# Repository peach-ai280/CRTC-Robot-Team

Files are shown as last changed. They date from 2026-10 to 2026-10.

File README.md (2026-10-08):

# CRTC2026 · 机器人总动员战队

重庆大学机器人训练大赛（CRTC2026）新生组参赛工程仓库。

## 📖 先看哪一份

| 你想知道什么 | 看这个 |
|---|---|
| **我们做到哪一步了、路上踩了哪些坑** | **➡ [`docs/工程日志.md`](docs/工程日志.md)** ← 主日志，按功能分板块写 |
| 进度总表、文档索引 | [`docs/00_总览与时间线.md`](docs/00_总览与时间线.md) |
| 用了哪些别人的东西 | [`docs/开源项目说明.md`](docs/开源项目说明.md) ← **中期提交必读** |
| 今天该干什么（内部备忘） | [`docs/现在该干什么.md`](docs/现在该干什么.md) |

---

## 关于文档规范（对照手册 4.3.1）

我们按手册要求组织文档，逐条对照如下：

| 手册要求 | 我们的做法 |
|---|---|
| 以 `.md` 格式提交 | 全部为 Markdown |
| 按设计进度**从早到晚**组织 | `docs/工程日志.md` 与各分册均按推进顺序排列 |
| **一个机器人功能 = 一个板块**，以**具体功能（H2 标题）+ 功能描述与开发历程**（正文）构成 | `docs/工程日志.md` 是主日志，每节 H2 即一个功能，正文分「功能描述」「开发历程」 |
| 每篇文档由**若干**上述板块组成 | 主日志含 11 个功能板块 |
| 用了开源项目须在**文档末尾完整说明** | 见 `docs/开源项目说明.md`，主日志末节也做了指引 |
| 仓库名用队伍名称的**英文/拼音** | `CRTC-Robot-Team`（Robot Mobilization） |
| 所有文档放在仓库根目录的 **`docs/`** 文件夹 | 根目录只留本 README，其余全在 `docs/` |

---

## 目录结构

```
CRTC-Robot-Team/
├── README.md                    本文件
├── docs/                        ★ 全部文档（中期考核「文档评估」提交内容）
│   ├── 工程日志.md               ★★ 主日志：11 个功能板块，一个功能一节
│   ├── 00_总览与时间线.md         进度总表、文档索引、真实性与开源说明
│   ├── 01_规则拆解与战术选型.md    得分规则量化、走桥战术、为什么放弃爬坡
│   ├── 02_机械结构与3D打印.md      尺寸红线核算、分层结构、打印件设计
│   ├── 03_底盘运动与麦轮防滑.md    麦轮解算、归一化限幅、死区、斜坡、电压补偿
│   ├── 04_电源硬件与焊接.md        电源树、继电器取电、DRV8833 改造、5V 塌陷
│   ├── 05_PS2手柄与遥控器.md       SPI 模式 3、DI/DO 接反、掉线保护、按键映射
│   ├── 06_舵机机构与抓取.md        序列器、舵盘转接板、夹爪、挑杆、探杆
│   ├── 07_方块携带与储仓.md        斜槽自锁、单向挡板、多项携带
│   ├── 08_半自动与视觉.md          机械对中 vs 视觉的选型、宏状态机、K210
│   ├── 09_结构稳定性成本与中期自查.md 跌落、尺寸复核、成本、考核自查表、视频脚本
│   ├── 开源项目说明.md           ★ 开源引用与许可，手册要求必写
│   ├── 进阶功能方案.md            3 项进阶功能 + 补买硬件清单 + 预算
│   ├── 调参指南.md                现场调参手册（分 8 步 + 症状速查 + 两套预设）
│   ├── 硬件接线与焊接指南.md       引脚总表、焊接点位、分步上电检查、故障速查
│   ├── 视觉模块选型与采购.md       K210 选型对比、接线、调试五步
│   ├── 半自动与全自动操作手册.md    三档模式怎么切、五个宏、全自动参数标定
│   ├── 代码说明_先看这个.md        代码文件导读
│   ├── 代码文件清单.md            逐文件清单
│   └── 现在该干什么.md            内部操作备忘（下一步清单）
├── firmware/                    ★ STM32 固件（C）
│   ├── Core/Inc/                   board.h 引脚映射 / config.h 全部可调参数 / 各模块头文件
│   ├── Core/Src/                   app.c 总调度 / mecanum.c 防滑 / motor.c 输出
│   │                               ps2.c / servo.c / arm.c / sensor.c / vision.c / auto_task.c
│   │                               bsp.c 时钟与外设初始化 / test_*.c 独立测试固件
│   ├── Core/Inc/hal_shim.h + Src/hal_shim.c   HAL 兼容层（纯寄存器，不依赖官方库）
│   ├── Core/Src/startup_stm32f103xb.c         用 C 写的启动文件（免官方汇编）
│   ├── STM32F103C8TX_FLASH.ld                 链接脚本
│   ├── 构建烧录与测试.md           一条命令出固件
│   ├── 烧录接口与ST-LINK说明.md    车上那 4 根 SWD 针怎么留
│   └── 编译与烧录指南.md           CubeIDE 图形化流程（备选）
├── cpp/                         ★ C++ 版运动 / 机械臂 / 视觉（离线验证，能在电脑上跑）
│   ├── README.md                  文件清单 + C vs C++ 的判断
│   ├── inc/crtc.hpp               类声明 + 参数结构 + 硬件抽象层接口
│   ├── src/                       chassis / motor / servo / arm / vision / params
│   ├── main_mcu.cpp                真机入口（串口命令，不接 PS2）
│   └── main_sim.cpp                离线自检用例（6 组断言）
├── mechanical/                  ★ 3D 打印件（参数化生成）
│   ├── gen_parts.py                结构件生成脚本（改尺寸改这里再重跑）
│   ├── gen_shell.py                外观套件生成器
│   ├── gen_gauge.py                底板量规
│   ├── 图纸集.html / 外观套件.html  带尺寸的图纸（浏览器打开）
│   ├── stl/*.stl                   25 个结构件
│   └── stl_pretty/*.stl            14 个外观件
├── 3D打印交付/                  ★ 拷去打印机就能开工（按批次分好文件夹）
│   ├── 打印机与耗材要求.md         机器能不能打的 4 条判定 + 耗材购买清单
│   ├── 打印前必读_金属底板适配.md   配 255×150 金属底板的三个必量数
│   ├── 切片与打印操作手册.md        零基础版：装软件→拖文件→填参数→切 gcode→上机
│   ├── 打印清单.csv               逐件的尺寸/重量/层高/填充/支撑
│   ├── 00_先打这个_量板规/ ~ 05_备件多打一份/
│   └── K1Max_G代码/               已切好的 G-code（K1 Max + PLA 直接打）
├── tools/                       ★ 自研工具链（本机没装 make / 切片软件，全自己写）
│   ├── build.py / build_cpp.py    一条命令编译
│   ├── flash.py                   一键烧录（check / motion / arm / vision / ps2 / full）
│   ├── slice_k1.py                自研切片器 → K1 Max 的 G-code
│   ├── check_gcode.py             切片结果逐行语法自检
│   ├── gen_step.py                导出 STEP（给机械队友改模型用）
│   ├── check_symbols.py           符号/宏静态自检
│   ├── print_bill.py              扫描 STL 出打印清单
│   ├── render_asm.py              用真实 STL 离线渲染装配示意图
│   └── sim/                       离线仿真（run_sim / run_auto_sim / run_cpp_sim）
└── vision/
    └── k210_find_cube.py          K210 MaixPy 色块识别（进阶功能备选）
```

---

## 三句话看懂我们的机器人

1. **两台一样的 4 轮麦轮车**（车体 236 × 162 × 148 mm；装收集铲后整车长 **283 mm**，
   红线 290 —— **只剩 7mm，是全车最紧的一条**）。
2. **1 号机走桥**抢中央高台的黄色能量核心（4 分 × 1.5 = 6 分），
   **2 号机在地面**扫 18 个白色能量单元（1 分 × 1.5 = 1.5 分/个）。
   **不走坡道** —— 麦轮在 26.6° 坡上会打滑，收益期望为负。
3. **半自动靠机械对中**（V 型口 + 双微动开关）而不是视觉，
   因为对中的失败模式是"没对准"（无害），视觉的失败模式是"对准了错的目标"（有害）。

---

## 技术栈与关键参数

| 项 | 值 |
|---|---|
| MCU | STM32F103C8T6 @ 72MHz |
| 底盘 | 4 × TT 马达(1:48) + 4 × 60mm 麦轮，轴距 180 / 轮距 136 mm |
| 驱动 | DRV8833 ×2（PHASE/ENABLE 接法），PWM 10kHz |
| 舵机 | MG995 ×1（大臂）+ SG90 ×3（夹爪/前铲/备用），PWM 50Hz |
| 遥控 | PS2 无线手柄，SPI 模式 3，281kHz |
| 电源 | 2 × 18650 串联（7.4V）→ 无线继电器 → 电机直供 + 5V 降压 |
| 控制周期 | 底盘 5ms / 舵机 10ms / 日志 200ms |
| 半轴距 / 半轮距 / 轮半径 | 0.090 / 0.068 / 0.030 m |

---

## 交付状态（截至 2026-10-08）

| 交付物 | 状态 |
|---|---|
| 开发环境与工具链 | ✅ **实测通过**（CubeIDE 2.2.0 + gcc 14.3.1 + 烧录器 + ST-LINK 驱动） |
| SWD 烧录链路 | ✅ **实测贯通**（`flash.py check` → `Device ID 0x410` / 3.21V） |
| 固件（底盘 / 防滑 / 机构 / 半自动 / 视觉接口） | 🟡 代码完成 + 离线仿真通过，**未上真车验证** |
| 3D 打印件 STL + 图纸集 | 🟡 模型完成（25 结构件 + 14 外观件），**未打印** |
| 接线表 / 焊接点位 / 上电检查 | 🟡 方案定稿，**未实际接线通电** |
| 工程日志 | ✅ `docs/工程日志.md` 主日志 + 15 份分册；标 `【待实测】` 处待实车回填 |
| 开源项目说明 | ✅ |
| 中期考核视频（1080p / 30fps） | ⬜ 待拍摄（脚本见 `docs/09`） |
| 规则测评（80 道单选） | ⬜ 待全队刷题库 |

---

## 提醒（给自己看的）

- 刷固件前**务必改 `config.h` 里的 `ROBOT_ID`**（1 = 1 号机，2 = 2 号机）。
- 所有 `【待实测】` / `【待回填】` 标记处，实车验证后必须替换成真实数据，**不能留着设计值冒充实测值**。
- 无线继电器**过了中期考核再买**（手册明确：未通过中期测评的队伍无需购买）。
- 中期提交截止 **2026-10-19 24:00**，收件 `zhang.guohao@lark.cquqian.li`。

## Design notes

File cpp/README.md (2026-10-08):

# C++ 版：运动 / 机械臂 / 视觉

> 这一套是应你"理论上应该用 C++"的要求写的。我在下面先把**该不该用 C++**
> 的判断讲清楚，再逐份说明每个文件是干什么的、你要对它们做什么。

---

## 一、先说判断：固件用 C 是对的，但不是因为"懒"

你说"理论上应该用 C++ 吧"——这个直觉**一半对一半不对**，我分开说：

**不对的一半**：STM32 固件本体用 C 是工程上的正解，不是退而求其次。

- HAL 库、CubeMX 生成的代码、ST 的所有例程全是 C API。用 C++ 只是给 C 函数包一层壳，没有实际收益。
- 关掉异常和 RTTI（否则 64KB Flash 顶不住）之后，C++ 能用的就只剩"类 + 内联"。而这套代码压根没有复杂的类层次，封装带来的收益接近零。
- 队友接手、老师检查代码时，C 的门槛低得多。

**对的一半**：**算法层和离线验证用 C++ 确实更好**。这也是我写这一套的原因：

1. **一套代码两个目标**。`hal_mcu.cpp` 和 `hal_sim.cpp` 是同一个接口的两份实现，同一份 `chassis.cpp` / `arm.cpp` / `vision.cpp` 换个文件就能在 PC 上跑。C 版做不到这点——C 版的仿真是另写了一份 `sim_kinematics.c`，等于同一套公式写了两遍，**真机代码和仿真代码会慢慢跑偏**，这是个真实的长期隐患。
2. 参数做成结构体，以后要"扫一组参数看哪个最好"很方便。
3. 类的边界（底盘 / 电机 / 舵机 / 序列器 / 视觉）比 C 版的文件划分更清晰，出问题好定位。

**所以结论**：两套并存，各干各的——

| 场景 | 用哪套 |
|---|---|
| 打比赛、接 PS2 手柄 | **C 版**（`firmware/build/full/firmware.bin`） |
| 学逻辑、改算法、离线验证参数 | **C++ 版**（这一套） |

⚠ **C++ 版目前没有接 PS2 手柄**，只收串口字符命令。它不替代 C 版，是给你验证和试参数用的。

⚠ **两套的参数必须同步改**：`firmware/Core/Inc/config.h` ↔ `cpp/src/params.cpp` 一一对应。只改一边会出现"同一个动作两套表现"的怪事。

---

## 二、上一轮给的那些文件，分别是啥？哪个才是要烧进去的？

**只有 `.bin`（或 `.hex` / `.elf`）是烧进芯片的东西。`.c` / `.h` / `.py` / `.md` 都不是**——它们是"原料"，编译之后才变成能烧的文件。

| # | 文件 | 它是什么 | 要烧吗 | 你要干啥 |
|---|---|---|---|---|
| 1 | `firmware/构建烧录与测试.md` | 说明书：怎么编、怎么烧、三个测试固件怎么用 | ❌ 不烧 | **照着做**。第一步就看这个 |
| 2 | `firmware/Core/Inc/config.h` | **全车唯一调参入口**，每个宏后面都写了"调大/调小的后果" | ❌ 不烧（它是被编进去的原料） | **调试期间 95% 的时间只改这个文件**，改完重编 |
| 3 | `tools/build.py` | C 版构建脚本（本机没 make，用 Python 直接调编译器） | ❌ 不烧 | 在**仓库根目录**敲 `python tools/build.py full`（别在 `cpp/` 里敲，那里没有 `tools/`） |
| 4 | `firmware/Core/Src/test_motion.c` | 底盘测试固件的**源码** | ⚠️ 编译后烧它的 `.bin` | 架空车，串口发 `w/a/s/d/q/e` 看轮子转向 |
| 5 | `firmware/Core/Src/test_arm.c` | 机构测试固件的**源码** | ⚠️ 编译后烧它的 `.bin` | 发 `1`~`7` 试姿态，`i/k` 微调角度 |
| 6 | `firmware/Core/Src/test_vision.c` | 视觉测试固件的**源码** | ⚠️ 编译后烧它的 `.bin` | 不接摄像头也能测：发 `t/y/n` 造自造帧 |
| 7 | `firmware/Core/Inc/hal_shim.h` | 我自己写的 HAL 兼容层（官方库下不下来） | ❌ 不烧（被编进去） | **不用动**。业务代码一行没改就跑起来了 |
| 8 | `firmware/build/full/firmware.bin` | **★ 唯一真正烧进芯片的文件**（完整版，带 PS2） | ✅ **就是它** | 用 CubeIDE 或 STM32CubeProgrammer 烧到 `0x08000000` |

### 四个 `.bin` 不是都要烧，是按阶段换

```
第 1 天  firmware/build/motion/firmware.bin  → 架空车，只验证底盘转对不转
第 2 天  firmware/build/arm/firmware.bin     → 只验证舵机和机构
第 3 天  firmware/build/vision/firmware.bin  → 只验证视觉串口解析
打比赛   firmware/build/full/firmware.bin    → 全部功能，接 PS2 手柄
```

每次换固件就是重新烧一遍，芯片里同一时刻只有一个程序。

---

## 三、C++ 版每一份文件：干啥的 + 你要干啥

| 文件 | 干什么的 | 你要对它做什么 |
|---|---|---|
| `cpp/inc/crtc.hpp` | 全部类的声明 + `Params` 参数结构 + 硬件抽象层接口 | 读一遍理解结构，**一般不用改** |
| `cpp/src/params.cpp` | 默认参数表（和 `config.h` 一一对应） | ⚠️ **标定后把实测值抄回这里** |
| `cpp/src/chassis.cpp` | 底盘四步管线：斜坡 → 限自转 → 麦轮逆解 → 归一化 | 一般不用改 |
| `cpp/src/motor.cpp` | 单轮输出：死区补偿 → 起步助力 → 电压补偿 → 拆 PWM/方向 | 一般不用改 |
| `cpp/src/servo.cpp` | 舵机限速缓动（防 5V 塌陷导致单片机复位） | 一般不用改 |
| `cpp/src/arm.cpp` | 八个动作脚本 + 串行动作序列器 | ⚠️ **舵机角度标定完抄回这里** |
| `cpp/src/vision.cpp` | 14 字节定长帧解析 + 自动对位的 P 控制 | 一般不用改 |
| `cpp/src/hal_mcu.cpp` | 硬件抽象层的**真机实现**（碰寄存器） | 不用动 |
| `cpp/src/hal_sim.cpp` | 硬件抽象层的**模拟器实现**（写内存） | 不用动 |
| `cpp/main_mcu.cpp` | 真机入口 + 串口命令表 + 主循环调度 | 想加串口命令改这里 |
| `cpp/main_sim.cpp` | 离线自检用例（6 组断言） | 想加测试改这里 |
| `tools/build_cpp.py` | C++ 版构建脚本 | 敲命令 |
| `tools/sim/run_cpp_sim.py` | 模拟器驱动（读日志 + 判 PASS/FAIL） | 敲命令 |

**一句话概括你要动的**：`params.cpp`（参数）+ `arm.cpp`（角度）+ 敲两条命令。

---

## 四、三条命令（可直接复制）

```bash
# 1. 编模拟器版 + 在 PC 上跑一遍自检（改完参数先用这个验证）
python tools/build_cpp.py sim
C:/Users/hp/.workbuddy/binaries/python/envs/default/Scripts/python.exe tools/sim/run_cpp_sim.py

# 2. 编真机固件（出 cpp/build/mcu/firmware.bin）
python tools/build_cpp.py mcu

# 3. 两个一起编
python tools/build_cpp.py all
```

第 2 条必须用那个带 unicorn 的 Python（装在 WorkBuddy 的虚拟环境里，没污染你的系统 Python）。

---

## 五、C++ 版固件的串口命令

烧 `cpp/build/mcu/firmware.bin`，串口 PA9/PA10、115200，**发一个字符即可，不用回车**。

```
运动： w 前进  s 后退  a 左移  d 右移  q 左转  e 右转  x 停  z 斜走45°  r 自动演示
机构： 1 收起  2 待命  3 地面取块  4 台阶取块  5 入仓  6 挑物资架  7 洞窟  8 放铲
微调： [ ] 夹爪∓5°   - = 大臂∓5°   , . 前铲∓5°   m 打印当前角度
视觉： v 造一帧测试数据（不接摄像头也能验证）   V 打印视觉状态
其他： h 帮助   0 急停解除
```

**微调完的角度要抄回 `cpp/src/arm.cpp`**（或 C 版的 `config.h`），否则下次烧录又回默认值——这是新手最容易白干的一件事。

---

## 六、模拟器实测数据（ARM 机器码真跑出来的，不是我推算的）

```
[1] 麦轮解算
  纯前进   [+0.850 +0.850 +0.850 +0.850]   四轮同号同值 ✓
  纯左移   [-0.850 +0.850 +0.850 -0.850]   LF/RB 负、RF/LB 正 ✓
  斜走45°  [+0.000 +1.000 +1.000 +0.000]   ← 注意这个
  三轴全给 [-0.218 +1.000 +0.564 +0.218]   |w|max=1.000（归一化生效）

[2] 方向保持：反算角 vs 期望角，误差 0.000°（全部用例）

[3] 斜坡：0 → 95% 用 270ms（理论 283ms）；松手 → 停住 145ms

[4] 死区：speed 0.05 → duty 0.341；0.50 → 0.710；1.00 → 1.000

[5] 地面取块序列：耗时 3970ms，同一时刻最多 1 个舵机在动 ✓

[6] 视觉：好帧解析正确（含负数坐标）；坏校验被丢弃；垃圾数据后能重新对齐
```

**斜走 45° 那行值得单独解释**：四轮解算是 `[0, 1, 1, 0]`，即**只有右前和左后两个轮在转**。这不是 bug，是麦轮的固有特性——纯对角线移动时只有一条对角线上的两个轮出力，另外两个轮速度为 0。看到这个不要以为是代码错了。

**3970ms 一个取块动作偏慢**，5 分钟一局大约能取 20 多个。想加快有两个旋钮：把 `servoDps` 从 240 提到 360（前提是不烧舵机、不拉塌 5V），或者把 `arm.cpp` 里各步的 `waitMs` 调小。建议先只改 `waitMs`，风险小。

---

## 七、这套代码我验证了什么、没验证什么

**已验证（本机实测）**：

- ✅ C++ 真机固件编译链接通过，25.3KB Flash / 3.3KB RAM（芯片 64KB，余量充足）
- ✅ 模拟器里执行真实 ARM 机器码，6 组断言全 PASS
- ✅ 运动学方向、归一化、斜坡、死区、序列串行性、视觉帧解析

**没验证（要你上电实测）**：

- ❌ 舵机角度——这是按机构几何推的初值，你的装法不同，必须在线标定
- ❌ 真机跑起来的实际表现（打滑、跑偏、夹不夹得住）
- ❌ 视觉对真实 K210（我只验证了自己造的帧能被正确解析）
- ❌ PS2 手柄——C++ 版根本没接，打比赛用 C 版

**上电前三条**：① 车架空 ② 电池 ≥7.0V ③ DRV8833 的 nSLEEP 接高。舵机听到"吱吱"声立刻断电，那是超行程在硬撑。

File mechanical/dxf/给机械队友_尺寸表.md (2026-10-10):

# CRTC2026 · 结构件尺寸表（交给机械队友）

> 单位 mm ｜ 材料 PLA ｜ 生成脚本 `mechanical/gen_parts.py`（改完重跑，图纸和 STL 同源，不会跑偏）
>
> **每个件都是「2D 轮廓 + 拉伸」**，所以一张 DXF 就是这个件的完整定义。
> 改图流程：用 SolidWorks / Fusion 360 / Creo 打开 `零件名.dxf` → 选中外面的闭合轮廓 →
> **拉伸到【厚度】那一列的数值** → 再把 DXF 里剩下的闭合小环（也就是孔）拉伸切除。
> 想一次看全部就用 `ALL_全部零件.dxf`，每个零件一个图层，图层名末尾带厚度。

## ⚠ 哪些尺寸不能动（规则红线，改了会判不过）

- **整车外廓**：初始状态 ≤ 290 × 195 × 210 mm（长×宽×高），变形后 ≤ 445 × 400 × 450
- **整车重量** ≤ 2.0 kg（目前预算 1076 g，余 924 g，余量建议拿去做底部配重）
- 甲板宽 162 mm 是贴着 195 上限留了余量，加宽前先确认还有多少裕度

## ✅ 哪些随你改（不影响规则）

- `01_deck_front` / `02_deck_rear` 上的**安装长圆槽**：这是给金属底板留的调节量，位置/长度随便调
- 所有减重孔的位置（只要别和安装槽、舵机槽撞在一起）
- 外观件（`stl_pretty/` 那批）全部不承重，随便改形状

## 📐 全车已经定死的机械接口（改了要同步改代码）

| 参数 | 值 | 谁在用 |
|---|---|---|
| 轮距 TRACK | 136 mm（半 68） | `firmware/Core/Inc/board.h` 的 `ROBOT_HALF_TRACK` |
| 轴距 WHEELBASE | 180 mm（半 90） | `board.h` 的 `ROBOT_HALF_WHEELBASE` |
| 麦轮外径 | 60 mm（半径 30） | `board.h` 的 `WHEEL_RADIUS` |
| 能量单元 | 30 mm 立方（V1.5），**六面各开 15×15 方口、内部贯通** | 夹爪闭合净距、收集铲喉口 50 mm |
| 机械臂平行杆轴距 AB_LINK_L | 105 mm | 臂长，改了够不到离地 250 的物资架 |
| 机械臂两轴距 AB_PITCH | 24 mm | 肩架竖板与肘座**必须同时**是 24 |
| 机械臂回转轴位置 AB_AX | 底板中心往前 106 mm | 收起时臂朝正后方平躺 |
| 机械臂轴高 A.z | 离地 164.5 mm | 收起态全车最高 196.5（红线 210） |
| 收起时爪子中心落点 | x = −17 mm（yaw 180°） | 储仓最后一列必须盖住这个点 |
| 储仓装车位置 | x ∈ [−32, +68]，y ∈ [−68, +68] | 中段立柱已挪到 x=−45/+78 让位 |
| 储仓有效容量 | 3 列 × 4 排 = 12 位，**最后列中两排留空** → 实装 10 块 | 那两格是爪子停车位兼投料口 |
| 安装长圆槽 | 中心 ±60，槽长 30，槽宽 4 | 只此一项和买来的金属底板有关 |

## 零件清单

| DXF 文件 | 中文名 | 数量 | 长 | 宽 | 厚度 | 估重 | 批次 |
|---|---|---|---|---|---|---|---|
| `01_deck_front.dxf` | 前段主甲板 | ×1 | 128 | 162 | 4.0 | 36.2 g | ① 底盘必打 |
| `02_deck_rear.dxf` | 后段主甲板 | ×1 | 128 | 162 | 4.0 | 38.3 g | ① 底盘必打 |
| `03_deck_splice.dxf` | 甲板搭接板 | ×1 | 60 | 60 | 3.0 | 5.9 g | ① 底盘必打 |
| `04_column.dxf` | 甲板立柱 | ×4 | 12 | 12 | 22.0 | 1.3 g | ① 底盘必打 |
| `05_scoop_floor.dxf` | 收集铲底板（V 型） | ×1 | 28 | 96 | 6.0 | 6.5 g | ② 收集与储仓 |
| `05b_scoop_wall_L.dxf` | 收集铲侧板（左） | ×1 | 28 | 29 | 26.0 | 2.3 g | ② 收集与储仓 |
| `05c_scoop_wall_R.dxf` | 收集铲侧板（右） | ×1 | 28 | 29 | 26.0 | 2.3 g | ② 收集与储仓 |
| `05d_scoop_back.dxf` | 收集铲后壁（对中挡板） | ×1 | 8 | 64 | 26.0 | 7.2 g | ② 收集与储仓 |
| `06_limit_lever.dxf` | 对中限位摆杆 | ×2 | 45 | 12 | 4.0 | 1.2 g | ③ 机械臂（柱坐标） |
| `07_grip_finger_L.dxf` | 夹爪指（左） | ×1 | 46 | 16 | 6.0 | 1.7 g | ③ 机械臂（柱坐标） |
| `08_grip_finger_R.dxf` | 夹爪指（右） | ×1 | 46 | 16 | 6.0 | 1.7 g | ③ 机械臂（柱坐标） |
| `24a_claw_base.dxf` | 平行夹爪·爪架底板 | ×1 | 74 | 56 | 4.0 | 4.6 g | 其他 |
| `24b_claw_slider.dxf` | 平行夹爪·滑块 | ×2 | 18 | 16 | 12.0 | 1.8 g | 其他 |
| `24c_claw_finger.dxf` | 平行夹爪·爪指 | ×2 | 6 | 26 | 34.0 | 2.7 g | 其他 |
| `24d_claw_horn.dxf` | 平行夹爪·舵机摇臂 | ×1 | 33 | 6 | 3.0 | 0.3 g | 其他 |
| `24e_claw_link.dxf` | 平行夹爪·连杆 | ×2 | 34 | 6 | 3.0 | 0.3 g | 其他 |
| `24f_claw_gear.dxf` | 齿轮夹爪·齿轮 | ×2 | 15 | 15 | 6.0 | 0.3 g | 其他 |
| `24g_claw_rack.dxf` | 齿轮夹爪·齿条滑块 | ×2 | 44 | 15 | 12.0 | 3.8 g | 其他 |
| `24i_claw_finger_gear.dxf` | 齿轮夹爪·爪指 | ×3 | 6 | 36 | 34.0 | 3.9 g | 其他 |
| `24h_claw_base_gear.dxf` | 齿轮夹爪·爪架底板 | ×1 | 74 | 56 | 4.0 | 3.8 g | 其他 |
| `26_cube_mock.dxf` | 能量块道具 30×30×30（镂空骨架） | ×4 | 30 | 30 | 30.0 | 7.4 g | 其他 |
| `30_arm_base.dxf` | 机械臂·回转底座（柱坐标） | ×1 | 64 | 44 | 40.0 | 15.2 g | ③ 机械臂（柱坐标） |
| `31a_arm_turntable.dxf` | 机械臂·回转盘（柱坐标） | ×1 | 64 | 44 | 6.0 | 6.9 g | ③ 机械臂（柱坐标） |
| `31b_arm_mast.dxf` | 机械臂·立柱（柱坐标） | ×1 | 40 | 40 | 62.6 | 15.5 g | ③ 机械臂（柱坐标） |
| `32_arm_carriage.dxf` | 机械臂·滑座（柱坐标） | ×1 | 52 | 52 | 32.0 | 10.9 g | ③ 机械臂（柱坐标） |
| `33_arm_boom.dxf` | 机械臂·爪横臂（柱坐标） | ×1 | 38 | 24 | 8.0 | 4.0 g | ③ 机械臂（柱坐标） |
| `34_arm_lift_crank.dxf` | 机械臂·升降曲柄（柱坐标） | ×1 | 18 | 28 | 8.0 | 1.4 g | ③ 机械臂（柱坐标） |
| `35_arm_lift_link.dxf` | 机械臂·升降连杆（柱坐标） | ×1 | 56 | 8 | 6.0 | 1.2 g | ③ 机械臂（柱坐标） |
| `36_arm_lift_cap.dxf` | 机械臂·顶帽（柱坐标） | ×1 | 60 | 60 | 6.0 | 7.1 g | ③ 机械臂（柱坐标） |
| `12_bin_floor.dxf` | 储仓底板 | ×1 | 100 | 136 | 3.0 | 22.0 g | ② 收集与储仓 |
| `13_bin_side.dxf` | 储仓侧板 | ×2 | 100 | 52 | 3.0 | 8.1 g | ② 收集与储仓 |
| `14_bin_divider.dxf` | 储仓隔板 | ×2 | 130 | 46 | 3.0 | 7.6 g | ② 收集与储仓 |
| `15_bin_flap.dxf` | 储仓单向挡板 | ×3 | 42 | 30 | 2.0 | 1.3 g | ② 收集与储仓 |
| `16_rack_hook.dxf` | 物资架挑杆头 | ×1 | 70 | 24 | 6.0 | 3.5 g | ③ 机械臂（柱坐标） |
| `17_cave_probe.dxf` | 洞窟探杆头 | ×1 | 92 | 20 | 6.0 | 3.8 g | ③ 机械臂（柱坐标） |
| `18_electronics_tray.dxf` | 电控托盘 | ×1 | 110 | 80 | 3.0 | 12.7 g | ① 底盘必打 |
| `19_battery_clip.dxf` | 18650 电池盒卡箍 | ×1 | 54 | 52 | 3.0 | 1.9 g | ① 底盘必打 |
| `20_bumper_front.dxf` | 前保险杠 | ×1 | 16 | 108 | 10.0 | 7.4 g | ① 底盘必打 |
| `21_anti_tip.dxf` | 防翻侧杆 | ×2 | 116 | 16 | 5.0 | 4.6 g | ① 底盘必打 |
| `22_ramp_anchor.dxf` | 坡道防滑撑地块 | ×1 | 48 | 24 | 8.0 | 4.7 g | ② 收集与储仓 |
| `23_cam_mast.dxf` | 视觉模块支架 | ×1 | 118 | 36 | 4.0 | 8.2 g | ③ 机械臂（柱坐标） |

## 联系与背景

重庆大学 CRTC2026 机器人训练大赛，新生组。电控这边已经把固件写完（STM32F103C8T6，
DRV8833 驱动、麦轮 X 型逆解、PS2 半自动 + 全自动），**不依赖任何 3D 件的精确尺寸**，
唯一的要求是上面那张「不能动的机械接口」表里的四个数别变。

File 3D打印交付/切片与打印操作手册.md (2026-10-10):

# 3D 打印：从 STL 到实物（零基础版）

> **⚠️ 先读 `打印前必读_金属底板适配.md`**（就放在同一层目录里）。
> 里面写了配你那块 255×150 金属底板要先量的三个数，以及全车唯一一个
> 必须对上的孔位（甲板立柱，140×100）。**那份读完再回来照这份点鼠标。**

> 这一份是给你（或帮你打印的学长）照着点鼠标用的。
> 全程不需要写代码，不需要懂建模。
> **唯一需要你先确认的一件事：你们那台打印机的牌子型号。** 写在下面，参数才好填准。

> 📦 **不知道机器能不能打、不知道买什么料 → 先看 `打印机与耗材要求.md`**（同一层目录）。
> 里面有：能不能用这台机器的 4 条判定、耗材照抄购买清单、为什么必须 FDM 不能用光固化。

---

## 0. 先回答三个问题（决定后面怎么填参数）

| 问 | 怎么确认 | 填什么 |
|---|---|---|
| 打印机型号？ | 看机身上的铭牌 | ______ |
| 打印床多大？ | 量一下能打的最大方块，常见 220×220 或 235×235 | ______ |
| 用的什么料？ | 看料盘上写的，通常是 **PLA** | ______ |

> 我们最大的件是 `02_deck_rear.stl`（128×162mm），**220mm 的床放得下**。
> 甲板之所以分成前后两段，就是因为一整块 236mm 超床了。

---

## 1. 装切片软件（三选一，装一个就行）

| 软件 | 费用 | 推荐度 | 下载 |
|---|---|---|---|
| **OrcaSlicer** | 免费 | ★★★★★ 首选，中文界面全 | 搜 "OrcaSlicer 官网" → GitHub Releases 下 Windows 版 |
| PrusaSlicer | 免费 | ★★★★ 稳，就是有些国产机没配置 | prusa3d.com |
| Ultimaker Cura | 免费 | ★★★ 老牌，机型多，界面稍旧 | ultimaker.com |

**装的时候会让你选打印机型号**——选你们那台。列表里找不到就选一个床尺寸一样的通用机型（比如 "Ender-3"，床 220×220），后面手动把床尺寸核对一遍。

---

## 2. 导入零件

1. 打开软件，左上角确认打印机型号对了
2. 把**这一批要打的**文件夹里的 `.stl` 全选，**直接拖进软件窗口**
   （第一批到底打哪个文件夹，看第 8 节——**不是**直接打 `01_底盘必打`）
3. 弹出"导入多个对象"→ 选 **"作为一个对象，包含多个零件"**（OrcaSlicer）或 "单个模型，多部件"（Cura）
   - 这样后面可以一个一个分开摆

> **不要一次导入全部 39 个。** 一次摆 5~8 个最好操作，摆错了也只重摆几个。

### ⚠ 导入前先看清"数量"——有些件要打好几个

`打印清单.csv` 里有**「数量」**这一列，别漏了：

| 批次 | 文件数 | **实际要打的件数** |
|---|---|---|
| ① 底盘必打 | 8 | **12** |
| ② 收集与储仓 | 9 | **13** |
| ③ 机械臂与机构 | 14 | **15** |
| ④ 外观套件 | 14 | 14 |
| 合计 | 45 | **54** |

比如 `06_limit_lever`（对中摆杆）要打 **2 个**（左右各一），
`07_grip_finger_L` / `08_grip_finger_R` 各 1 个（注意是左右两件、不是同一个件打两个）。

⚠ 上面这张表以 **`打印清单.md` 为准**（那份是脚本生成的，本手册写到后面可能会滞后）。
零件数变了就重跑 `python tools/print_bill.py` 刷新。

**在切片软件里怎么打多个**：选中那个件 → 右键 → **"复制" / "Multiply" / "数量"** → 填 2 或 3，
软件会自动摆开。**不要**分两次切片打，那要重新预热两遍，慢一倍。

另外有 5 个件标了 **「建议多打一份」**（`05_备件多打一份` 文件夹里的）：
立柱、对中摆杆、夹爪指×2、舵盘转接板。这几个是摔断/滑牙的高发件，
多打一份放在工具盒里，赛场上断了能直接换。

---

## 3. 摆放（这一步最容易出错，认真看）

### 三条铁律

**① 最大的那个面朝下贴床。**
薄板件（甲板、储仓底板、侧裙）本来就是平躺的，导入后点一下工具栏的 **"放到平台上"**（图标是个小方块落到网格上），软件会自动摆正。

**② 别让件悬空。**
悬空的部分打印时需要支撑，拆支撑很麻烦还留疤。所以：
- 夹爪指、对中摆杆这种细长件 → **躺着放**，别立着
- 轮眉是弧形的 → **开口朝上**放（弧顶朝下贴床）

**③ 件和件之间留 5mm 以上。**
挨太近会粘在一起，掰开时容易断。

### 快速摆放按钮（OrcaSlicer）

左工具栏从上往下：
- 第 2 个 **移动** → 选中件拖动
- 第 3 个 **缩放** → **不要动！** 我们给的尺寸就是实际尺寸，缩放错了装不上
- 第 4 个 **旋转** → 点件，选 **"放到平台上"**（自动躺平）
- 第 5 个 **分割/排列** → 点 **"自动排列"**，软件帮你把件铺满一床

---

## 4. 打印参数（照抄，别自己改）

在右侧参数面板里选 **"0.20mm 标准"** 这类预设，然后手工核对这几项：

| 参数 | 填什么 | 为什么 |
|---|---|---|
| 层高（Layer height） | **0.20mm**（外观件 0.16mm） | 0.2 是强度和速度的平衡点；0.1 太慢，0.3 太糙 |
| 壁厚 / 外壳圈数（Wall loops） | **3 圈** | 少于 2 圈一掰就裂 |
| 顶部/底部层数 | **4 层** | 薄板件的强度全靠它俩 |
| 填充密度（Infill） | **25~30%**（外观件 15%） | 受力件别低于 25%；外观件不承重，15% 省料省时 |
| 填充图案 | **网格 / Grid**（或 Gyroid） | 三向受力都扛得住 |
| 支撑（Support） | **关**（大件开"边缘支撑/brim"） | 我们的件都设计成不用支撑的；大件怕翘边就加 **Brim 8mm** |
| 喷嘴温度 | **200℃**（PLA，第一层 205） | 料盘上写了就按料盘 |
| 热床温度 | **60℃**（第一层 65） | 低于 55 会翘边脱落 |
| 打印速度 | **50~60 mm/s**，首层 **20 mm/s** | 首层慢是粘床的关键 |
| 冷却风扇 | **100%**（首层 0%） | 首层开风扇会翘 |

> 这些数在 `docs/02_机械结构与3D打印.md` 里也有，那里还有我们踩过的坑。

---

## 5. 切片 & 导出

1. 右上角点 **"切片"**（Slice）
2. 等几秒，下方会显示 **预计用时** 和 **用料克数** ← **这两个数记下来，填回 `打印清单.csv`**
3. 切片完会显示层预览，拖滑块看一遍：
   - 有没有大片悬空没支撑
   - 首层铺得实不实
4. 点 **"导出 G-code"**（或"保存到可移动驱动器"）
5. 存成 `01_deck.gcode` 这种名字，拷到 **SD 卡根目录**（不是文件夹里）

---

## 6. 上机打印

1. SD 卡插打印机
2. 屏幕选 **Print from SD** → 找到文件名 → 确认
3. **前 5 分钟别走开**，盯着首层：
   - 丝均匀地压在床上、边缘不翘 → 成了，可以走
   - 丝卷成球 / 挤出不来 → 立刻停，床没调平或喷嘴太高
4. 打完等床降到 **40℃ 以下**再取件（热的时候取会变形）
5. 取不下就用铲刀慢慢撬，**别硬掰**

---

## 7. 打完之后：试装（这一步一定做）

打完第一批底盘件，立刻拿螺丝试装：

- **M3 孔插不进螺丝** → 正常，用 **3mm 钻头**手动扩一下（打印件孔会缩）
- **孔位对不上** → 先用记号笔描一下再扩成长孔，别推倒重打
- **件太松** → 加个 M3 螺母或垫片

> 打印件有 ±0.2mm 的误差是**正常的**，不是设计错了。
> 我们的孔都故意留了余量，就是给你扩的。

---

## 8. 打印顺序（照这个来，一件都不会白打）

> ⚠️ **先看这条**：`01_底盘必打` 里有 **3 个"尺寸还没定死"的文件**——
> `01_deck_front`、`02_deck_rear`、`04_column`。它们的立柱槽位（±45~75mm 长圆槽）和立柱高度（22mm）
> 取决于你手上那块金属底板的**实测宽度和离地高度**（见 `打印前必读_金属底板适配.md`）。
> 先打它们有白打的可能（两块甲板 77g / 4~5 小时，是全车最贵的件），所以把第 0 批提到最前。

| 序号 | 打什么 | 在哪 | 文件 / 件数 | 约重 | 大约用时 |
|---|---|---|---|---|---|
| **0** | **量板规（必须最先）** | `00_先打这个_量板规/` | 3 文件 / 3 件 | <20 g | 8 分钟 |
| **1** | 底盘里**不依赖板宽**的 6 件 | `01_底盘必打/` | 5 文件 / 6 件（见下表） | ≈ 43 g | 2~3 小时 |
| **2** | 收集与储仓 | `02_收集与储仓/` | 8 文件 / 12 件 | 91 g | 5~7 小时 |
| **3** | 机械臂与机构 | `03_机械臂与机构/` | 9 文件 / 12 件 | 40 g | 4~6 小时 |
| **4** | **等量规结果再打** | `01_底盘必打/` | 3 文件 / 6 件 | 81 g | 4~5 小时 |
| **5** | 备件 | `05_备件多打一份/` | 5 文件 / 5 件 | ≈ 15 g | 2 小时 |
| **6** | 外观套件 | `04_外观套件/` | 14 文件 / 14 件 | 72 g | 6~8 小时 |

> 注：第 5 批里的 `04_column.stl`（立柱备件）和第 4 批的立柱是同一个件，
> 同样要等量规结果；其余 4 个备件（摆杆、夹爪指×2、舵盘转接板）随时可打。

### 第 1 批具体打这 6 件

从 `01_底盘必打` 里只挑下面 5 个文件，**其余 3 个先别动**：

| 文件 | 件数 | 是什么 |
|---|---|---|
| `18_electronics_tray.stl` | 1 | 电控托盘 |
| `19_battery_clip.stl` | 1 | 18650 电池卡箍 |
| `20_bumper_front.stl` | 1 | 前保险杠，**加 Brim 8mm** |
| `21_anti_tip.stl` | 2 | 防翻侧杆，左右各一 |
| `03_deck_splice.stl` | 1 | 甲板搭接板（垫在接缝下的方块，不受板宽影响）|

**第 4 批（等量规）**：`01_deck_front`、`02_deck_rear`、`04_column`×4。
量完把四个结果发出来，参数定稿、重出图之后这几件再打——**前面打的件一件都不会白费**。

> 文件数 ≠ 件数：对中摆杆打 2 个、舵盘转接板 3 个、储仓侧板/隔板各 2 个……见第 2 节数量表。

> **外观件一定最后打。** 中期考核看的是功能，外壳再漂亮、车跑不起来也是 0 分。
> 而且外观件装完要重新称重（限重 2.0kg），早装了反而碍事。

## 9. 打完要称一次总重

**整车限重 2.0kg。** 打印件估算总重 **324g**（39 个文件 / 实际要打 50 件）。

整车重量是逐项算出来的，不是拍脑袋：

| 项目 | 小计 |
|---|---|
| 3D 打印件（50 件） | 324 g |
| 金属底板 255×150×1.5 铝板 | 155 g |
| TT 马达 ×4 + 麦轮 ×4 | 312 g |
| 电池 ×2 + 电池盒 | 105 g |
| 舵机（MG995 ×1 + SG90 ×3） | 82 g |
| STM32 / DRV8833 ×2 / PS2 接收头 | 24 g |
| 洞洞板、线材、螺丝、开关、杂件 | 74 g |
| **合计** | **≈ 1076 g** |

**距 2.0kg 上限还余约 924g。** 这个余量是**要主动用掉的**——麦轮车重心越低越防滑，
按 `docs/02` 的建议再配 200~300g 底部配重后约 1326g，仍有 674g 余量。

> ⚠ 早期这里写"1.6~1.9kg"是高估了，会导致你不敢加配重、车太轻反而打滑。
> 电子件按典型值估，**装完第一件事就是上秤**，实数填回 `docs/09`。

**装完外观件后必须实称一次。** 超了就按这个顺序拆：
1. 顶盖（约 16g）
2. 尾板 + 三角支臂（约 4g）
3. 侧裙（约 15g）

---

## 10. 常见翻车现场

| 现象 | 原因 | 怎么办 |
|---|---|---|
| 首层就翘起来、脱落 | 床没调平 / 床温低 / 首层有风扇 | 重新调平，床温 60，首层关风扇，加 Brim |
| 件中间裂开一道缝 | 填充太低或圈数太少 | 填充提到 30%，壁厚 3 圈 |
| 表面一层一层的、有疙瘩 | 料受潮了 | PLA 受潮要烘干（60℃ 烤箱 4 小时）或用新料 |
| 打出来尺寸偏小，孔更小 | 正常收缩 | 3mm 钻头扩孔 |
| 细长件立着打，一碰就断 | 摆放方向错了 | 躺着打，层纹方向要顺着受力方向 |
| 半途堵头、不出丝 | 喷嘴温度低 / 有杂质 | 升温到 210 试试，不行换喷嘴 |

---

## 附：文件夹说明

```
3D打印交付/
├── 切片与打印操作手册.md   ★ 打开这个，照着点鼠标
├── 打印清单.csv            用 Excel 打开：批次/数量/尺寸/重量/切片参数，打完填实测
├── 打印清单.md             同一个清单的 Markdown 版
├── 图纸集_结构件.html       25 个结构件的尺寸图（浏览器打开）
├── 图纸集_外观套件.html     14 个外观件说明 + 配色建议
├── 00_先打这个_量板规/     3 个 .stl（工装）     **★ 第一个打这个，8 分钟**
├── 01_底盘必打/            8 个 .stl（实际 12 件）  **⚠ 其中 3 个文件等量规结果再打**
├── 02_收集与储仓/          8 个 .stl（实际 12 件）
├── 03_机械臂与机构/        9 个 .stl（实际 12 件）
├── 04_外观套件/           14 个 .stl              最后打
└── 05_备件多打一份/        5 个 .stl              易损件，各多打一份
```

**每个 `.stl` 都已经是毫米单位的实体模型**，拖进切片软件就能用，不需要再转换。

**清单和图纸是同一套源生成的**（`mechanical/gen_parts.py` + `gen_shell.py` → STL → 清单），
所以数字不会打架。改动脚本后重新跑一遍，两边会一起更新。

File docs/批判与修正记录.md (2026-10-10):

# 批判与修正记录（机械臂方案）

> 这一篇记的是：机械臂方案从第一版到现在这一版，**被推翻和修正过哪些东西、为什么**。
>
> 之所以要单独记一篇：这份方案里几乎每一个数字都不是一次算对的，而是**先算出一个值、
> 再用脚本验算、发现装不上或者够不着、再改**，来回四轮。这些"错过的版本"本身
> 就是有价值的开发历程 —— 我们想保留它，而不是只留下一份看起来天生正确的图纸。
>
> ⚠⚠ **阅读提示（2026-10-10 加）**：本文件**最后一大节（"10-10 第三次大改"）之前的内容
> 全部属于「平行四连杆摆动臂」时期，现已整体作废**，只作为开发过程保留。
> 现行方案是**圆柱坐标机械臂**，请直接看文件末尾那一节。
>
> 验算脚本：`tools/check_arm_clearance.py`（纯 `math`，用 `D:\WorkBuddy\tools\python\python.exe` 跑）。
> 参数真源：`mechanical/gen_parts.py` 第 5.7 节 ←→ `tools/render_asm.py` 的 `CY_*` ←→ 上面那个脚本，
> **三处必须一致**。

---

## 机械臂摆臂行程：主臂杆长从 90 改到 105

**【原来的想法】** 主臂 A→B 的孔距取 90 mm。

**【错在哪】** 90 mm 的臂，把摆角顶到固件上限 +90°，夹持缝最高也只到 243 mm 左右，
而物资架上的黄块**质心离地 250 mm、块体占 235~265**。结果是**完全够不着**，
连"夹住下半截"都做不到 —— 这条路线直接作废。

**【怎么改】** 杆长 90 → **105 mm**。同时确认高度栈还有余量（改完全车最高点 196.5，红线 210）。

**【改之后是什么样】** 现在 φ=+90° 时夹持缝是 `[218.5, 252.5]`，与黄块 **重叠 17.5 mm**。
也就是说：从"完全够不着"变成了"**够得着，但只夹得住它下半截**"。
这一条仍然不理想，所以**用户已明确同意：物资架上的黄块实在取不下就放弃**。

**【证据】** `tools/check_arm_clearance.py` → `phi_window(235, 265)` 返回"无理数解"，
并打印出 φ=90° 时的重叠量 17.5 mm。

---

## 机械臂收起姿态：从「朝前下倾 45°」改成「朝后平躺」

**【原来的想法】** 不工作时让臂**朝前**下倾 45° 收在车头，觉得这样"看起来最紧凑"。

**【错在哪】** 两条，都是硬伤：
1. **车长爆表**。臂朝前伸出去，爪子会落到 x = +152 附近。车长从 283 直接冲到 **300 mm**，
   超过 **290 mm** 的红线 —— 检录直接不合格。
2. **撞收集铲**。车头 x = +124.5~+152.5 那一段是前铲的地盘，臂下倾必然和铲抢空间。

**【怎么改】** 改成 **yaw = 180° 朝正后方 + 摆角 φ = 0° 水平平躺**。
臂整条躺在车体上方，车长**还是原来的 283**（金属底板 255 + 铲 28），
离红线剩 7 mm，和"没装臂"一模一样。

**【代价】** 车高由竖板顶 196.5 决定（余 13.5 mm），这个可以接受；
但**引出了下一个问题** —— 爪停到车尾，就撞上了原来放在车尾的储仓（见下下条）。

**【证据】** `tools/check_arm_clearance.py` → `bbox_stow()`：
全长 282.5 mm、全高 196.5 mm、爪最低点 113.5 mm。

---

## 臂座长度：刻意做扁到 34 mm

**【原来的想法】** 臂座按"能装下 MG995"来做，取 50×74×50。

**【错在哪】** 臂座沿车长方向的长度一旦做长，**主臂往下摆的时候会打到臂座自己的前壁**。
φ 刚到 −26°（焦点取块位）就被自己挡住。

**【怎么改】** 臂座沿车长方向的长度**刻意压到 34 mm**（`AB_BASE_L = 34`），
只保证 MG995 侧躺着放得进去。宽向不受限，取 74。

**【副作用与对策】** 座子做扁了，MG995 就只能**侧躺**放，
于是轴心必须抬高 ≥ 本体半高（18 mm）才能让本体坐在回转盘面上 —— 这条直接决定了高度栈。

---

## 臂座 y 向必须偏置（12 / 20）

**【原来的想法】** 竖板、主臂、平行杆、肘座全部居中（y = 0 附近），觉得"对称好看"。

**【错在哪】** MG995 侧躺后的本体占 **y ∈ [−8, 12]、z ∈ [146.5, 182.5]**，
而竖板和主臂都要经过这一带 —— **三件东西抢同一块空间，物理上重叠**。

**【怎么改】** 沿车宽方向**刻意错开**：
- 肩架竖板 `AB_Y_MAST = 12` → 占 y ∈ [12, 20]
- 主臂 / 平行杆 / 肘座 `AB_Y_LINK = 20` → 占 y ∈ [20, 28]
- 爪居中

MG995 本体躺在 y ∈ [−8, 12]，正好**从竖板内侧让过去**。
代价是**整个臂组比车体中面偏了 20 mm**，略有一点点偏载，但 2 kg 的车可以忽略。

**【给装配的人】** 装配时**不要"顺手把臂挪正"** —— 挪正就是三件重叠。

---

## 高度栈：MG995 轴心抬升量 10 改到 18

**【原来的想法】** `AB_SERVO_DZ = 10`（MG995 轴心比回转盘面高 10 mm）。

**【错在哪】** MG995 侧躺时**本体高 36 mm**，轴心在正中间 → 半高就是 18 mm。
取 10 的结果是**本体下沿比盘面低 8 mm，扎进回转盘里** —— 装不进去。

**【怎么改】** `AB_SERVO_DZ = 18`。连带重算：主臂轴 A.z = 146.5 + 18 = **164.5**，
从动轴 A′.z = 188.5，竖板顶 **196.5**（红线 210，余 13.5）。

**【纪律】** 这个数**只能加不能减**。改了要连带 `31b_arm_mast` 高度、全车最高点一起重算。

---

## ★★★ 储仓位置：爪指会扎进旧储仓（数值验算抓出来的）

**【原来的想法】** 储仓放车尾，占 `x ∈ [−118, −18]`。
当时的判断是"平躺的臂在甲板上方，爪底 119.5 < 储仓顶 135.5，
**二维看不相交**，所以没事"。

**【错在哪】** 这个判断是**错的**，而且错得很隐蔽 —— 因为它把爪的**宽度**忽略了。
臂收起时 yaw=180° 朝后，以回转轴 `AB_AX = 106` 为圆心、水平伸出 `18 + 105 = 123` mm，
**爪子中心落在 x = 106 − 123 = −17**。而爪有**两根手指**，分别在：

- 手指 1：`x ∈ [−36, −30]`，`z ∈ [113.5, 147.5]`
- 手指 2：`x ∈ [−4, 2]`，`z ∈ [113.5, 147.5]`

这两根手指正好**插进储仓最后一列方块的上方 8 mm** ——
撞的是位置 **(2,1)** 和 **(2,2)** 这两格。装上车就是"爪子里卡着两块方块收不回去"。

**【怎么改】** 三条一起做（缺一条都不行）：

| | 改法 | 效果 |
|---|---|---|
| **a** | 储仓**整仓前移**到 `x ∈ [−32, +68]`（原 `BIN_X0 = −118`） | 爪停靠点 −17 落进仓内，不再落在仓尾外 |
| **b** | 中间那 4 根立柱从 `x = ±4` 挪到 **`x = −45 / +78`** | 把甲板中段整块让给储仓（最大无支撑跨距 120 mm，3 N 载荷下垂 ≈0.05 mm，可忽略） |
| **c** | 储仓**最后一列的中两排刻意留空**（`BIN_SKIP = ((0,1),(0,2))`） | 那两格就是爪子的停车位兼投料口 → 12 位里只用 10 位 |

**【改完之后】** 复算 **0 干涉**。而且捡到一个意外好处：爪的停靠点 x = −17 正好在
储仓**最后一列正上方**，张口时方块从 z≈113 掉到仓底 91.5，
**落差只有 22 mm** —— 这是全仓最温和的投料位（另两列要靠 48°/68° 摆角才能对准，落差 100~120 mm，
所以仓底还必须垫 3 mm EVA 减震）。

**【证据】** `tools/check_arm_clearance.py`：
- 旧方案 `x∈[−118,−26]` → `✗ 撞了 2 个方块位（位(2,1)/(2,2) 被手指1 压住）`
- 新方案 `x∈[−32,60] + 留空 ((0,1),(0,2))` → `✓ 全部无干涉`

**【教训】** 判断"两件东西会不会打架"，**只看一个剖面的高度是不行的**，
必须把三维包围盒都算进去。这就是为什么后来专门写了脚本、而不是靠看图纸判断。

---

## ★★ 验算脚本自己的 Bug：yaw 被旋转了两次

**【原来的想法】** 第一版 `check_arm_clearance.py` 写完，跑出来结论是
"旧储仓位置 ✓ 不干涉" —— 于是差点就这么交付了。

**【错在哪】** 脚本里 `elbow()` 先转了一次 yaw，`claw_boxes()` 里**又转了一次**。
双重旋转 180° = 转回 0°，等于**根本没转**，所以算出来的爪还在车头朝前的位置，
当然不撞车尾的储仓。同时还把肘座中心算成了 x = 242（正确值是 −17）。

**【怎么改】** 抽出 `_yaw_box(bx, yaw_deg)`，统一**只在 yaw=0 坐标下把整组爪搭好、
最后整组转一次**，与 `render_asm.arm_items()` 的摆法严格一致。

**【证据】** 修好后正确的输出就是上面那条：**旧位置会撞 2 格**。

**【教训】** 这是本次最贵的一个 Bug —— 它给出的不是"算错一个数"，而是**一个方向相反的结论**。
一个验证脚本，如果它自己没被验证过，它比不验算更危险。

---

## ★★ 判定标准改严：从「夹持区有重叠」改成「整块必须进缝」

**【原来的想法】** 只要爪的夹持区和方块**有重叠**，就算"能拿"。

**【错在哪】** 这个判据太松，掩盖了真问题。按它算，"物资架黄块"是 ✅ 的，
因为确实重叠了 —— 但实际只重叠 17.5 mm，**方块一半还在外面**，
一抬臂就掉。这个判据会让方案带着一个致命缺陷通过评审。

**【怎么改】** 改成严格判据 `phi_window(cube_lo, cube_hi)`：
要求 **夹持缝下沿 ≤ 方块底面** 且 **夹持缝上沿 ≥ 方块顶面**，
即 30 mm 的方块要**整块**落进 34 mm 的缝里。
公式：`E.z ≥ cube_hi + 29` 且 `E.z ≤ cube_lo + 63`（E.z 为肘座中心高度）。

**【改之后】** 物资架如实报出 **✗ 无理数解**（重叠 17.5 mm），
其余四个能用场景给出精确的 φ 窗口（台阶面 18.0~20.3°、高台面 9.6~11.8°、
焦点 −26.9~−24.5°），地面块如实报"需要 φ≤−60°，做不到"。

---

## 甲板：从「重叠 20 搭接」改成「端面对接」

**【原来的想法】** 前后两段甲板各 128 mm 长，**重叠 20 mm** 搭接，总长算 236 mm。

**【错在哪】** 两块甲板都是 **4 mm 厚的实体**，**不可能占同一段空间**。
重叠 20 在图纸上"看起来"接上了，装配时物理装不进去。

**【怎么改】** 改成**端面对接**：`01_deck_front` 放 `trans −1.0`、
`02_deck_rear` 转 180° 后放 `trans +1.0`，**装车总长 254 mm**，
正好压在 255 mm 的金属底板上。接缝下方仍垫 `03_deck_splice` 搭接板（从下往上 M3×8 穿）。

**【证据】** `tools/render_asm.py` 里的两行 trans 值。

---

## 储仓 5° 斜底：无效设计，改成垫 EVA

**【原来的想法】** 把储仓底板做成前低后高、整体抬高 5°，让方块自己往仓口滚。

**【错在哪】** PLA 与 PLA 之间的摩擦角约 **19°**。
**5° < 19°**，方块在 5° 斜面上**根本不会滑动**。这个设计既占了空间又没有任何作用。

**【怎么改】** 仓底改**平放**，改成**垫 3 mm EVA / 鼠标垫**：
- 解决"后两列投料落差 100~120 mm"的减震；
- 顺便解决急停时方块在仓里窜动。

---

## 取块能力的两个「做不到」，如实写进方案

这两条不是"改好了"，而是**明确承认做不到**，并把它们从方案里排除掉：

| 目标 | 为什么做不到 | 替代方案 |
|---|---|---|
| **地面白块**（相对车底板 0~30） | 要 φ ≤ −60° 才够得着，但 **−50° 以下主臂就扫到收集铲**，机械上没空间 | **全部交给前铲**（○ 键 / R1） |
| **洞穴黄块**（洞内） | **爪外宽 74 mm > 洞宽 70 mm**，爪根本进不去 | **洞窟探杆 `17_cave_probe`** |

**【为什么要写出来】** 手册的中期考核是"**做不到的不报不扣分**"，
但把做不到的东西含糊地写成"尽力争取"，是一颗定时炸弹 ——
评审时被问一句就穿帮。不如现在就写清楚。

---

## 第 5 路舵机的通道：TIM3 方案整个作废

**【原来的想法】** 臂要回转，需要第 5 路 PWM。
查表发现 **TIM3 全空闲**，结论是"TIM3 就是第 5 路舵机的唯一出路"，
还写了要"使能 AFIO 时钟、禁 JTAG、让出 PB0/PB1/PB5"。

**【错在哪】** 这个"空闲"是**只看了定时器、没看引脚**得出的 —— **TIM3 的三组引脚全部撞车**：

| TIM3 引脚组 | 撞上了什么 |
|---|---|
| 不重映射（PA6 / PA7） | **PS2 的 MISO / MOSI** |
| 部分重映射（PB4 / PB5 / PB0 / PB1） | **按键 / PS2 片选 / 电池 ADC** |
| 全重映射（PC6~PC9） | **蓝丸板（STM32F103C8T6）根本没引出这几个脚** |

**【怎么改】** 改用 **TIM1_CH4 = PA11**：不用重映射、不撞任何外设、板上引出来了。

**【连带要处理的】** TIM1 是**高级定时器**，不置 `BDTR.MOE`（bit15）
**所有通道会被硬件强制关断** —— 寄存器全配对了、示波器上也没波形。
已在 `hal_shim.c` 的 `HAL_TIM_PWM_Init()` 里补上。

**【新发现的坑】** PA11 / PA12 同时接在蓝丸板的 **micro-USB 座（D− / D+）** 上，
所以**调车时不能插 micro-USB 供电**。

**【教训】** 选引脚不能只看"这个外设空不空"，必须**把引脚和已有外设逐一对照**。

---

## 参数表里的三处残留：注释比代码更容易骗人

这三处都**不影响生成出来的零件**，但会误导下一个读代码的人（很可能就是三天后的自己）：

| 位置 | 残留内容 | 已改成 |
|---|---|---|
| `gen_parts.py` `BIN_X0 = −118.0` | 注释说"储仓前端的位置" —— 其实**没有任何几何在用它**，是旧布置的死参数 | 标注已作废，指明现方案见 `render_asm.py` 的 `BX0 = −32` |
| `gen_parts.py` `DECK_SEG_L` 注释 | "两段 + 20 搭接 = 236" | 改成"端面对接，装车总长 254" |
| `gen_parts.py` `31b_arm_mast` 的说明 | 还写着旧臂座位置 `x = 169.5` | 改成"回转轴在 `x = AB_AX = 106`" |
| `gen_parts.py` `AB_*` 一带的批量文案 | `120mm 轴距` / `132×116 的大底板` / `BIN_L(138) > DECK_SEG_L(128)` 等旧数字 | 全部按现参数改（一次性脚本 `str.replace`，miss = 0） |

---

## 小结：这一版方案现在站在什么位置上

**已经验算过的（可以在电脑上确认的）**

- 全车最高点 196.5 < 210 ✅、收起后全车长 282.5 < 290 ✅
- 收起姿态与储仓 **0 干涉**（脚本复算）
- 五个取块场景的 φ 窗口全部给出精确区间
- 固件 5 路舵机编译通过（`build.py all`）+ 符号表全绿 + nm 确认关键符号进了 elf

**还没验证的（必须上车实测，写进 `docs/` 时要标【待实测】）**

1. 臂回转 180° 后，爪是不是**真的**落在储仓停车位上方（`x = −17`）
2. 收起态实际总高是不是 196.5（打印件 + 螺钉 + 舵机线缆会吃掉一点余量）
3. 夹爪闭合后的实际净距是不是 26~28 mm
4. 物资架黄块用"先拨再夹"到底能不能拿下来
5. 摆角 −50° 时主臂离收集铲还剩多少间隙

**已知仍然不理想、但决定接受的**

- 物资架黄块只能夹下半截 → 取不下就放弃（已确认）
- 开环舵机末端精度 ±5~10 mm → **不把"精准抓取"报进阶功能**

---

# ★★★ 10-10 第三次大改：构型本身读错了，整套推翻重做

> 上面那一整节（平行四连杆摆动臂）现在**全部作废**。
> 起因是队长看了参考视频后说"你刚刚完全解读错了" —— 复核后确认：**确实读错了**。
> 视频里那台是**圆柱坐标机械臂**（柱坐标 / Cylindrical Robot），不是摆动臂。
> 这一节记录这次翻车，以及推翻后重新验算的过程。

## 一、解读错误：把"柱坐标"读成了"平行四连杆摆动臂"

**错在哪。** 我照着视频截图的几个姿态，反推出"两根等长杆 + 肘座"的平行四边形结构，
并且很自信地写进了文档、画了图、定了零件名（`09_arm_upper` / `10_arm_fore` / `25_arm_riser`…）。

**为什么错。** 平行四连杆的特征是**肘座姿态恒定、末端走圆弧**；
视频里那台机器的末端是**沿一条竖直线上下**走的 —— 这是柱坐标（旋转 + 升降 + 夹爪）的典型特征。
两者在单张截图上都表现为"一节一节"的机构，但**运动轨迹完全不同**。
我拿"结构长得像"当成了"机构就是它"，这是最典型的看图猜机构。

**代价。** 5 个零件作废、图纸集/装配图/交付包/固件角度表全部重做。
所幸零件还没开打，损失只有时间。

**教训（写进纪律）。** 判断一个机构的构型，**不要看静止的外观，要看末端在动的时候怎么动**。
只有单张截图时，宁可先问"这一段是转还是滑"，也不要凭外形下结论。

## 二、新构型定下来之后，验算又连续抓出 5 个致命错误

新构型是 **θ 回转 + Z 升降 + 夹爪开合**，三个自由度解耦、不需要逆解。
但把它"装起来"这件事，比画单个零件难得多。以下 5 个错误**全部是我自己在写代码时抓出来的**，
每一个都会导致"零件打出来了但装不上"：

### 2.1 升降舵机画在回转盘上 → 曲柄滑块根本闭合不了

**症状。** 第一版把升降舵机放在回转盘上（z ≈ 140），连杆画过去看似接得上。

**原因。** 曲柄滑块的销孔距（连杆长 L）是**恒定**的，于是滑座位置被曲柄角唯一决定：

```
z_s = CY_CRANK_Z + R·sinφ − sqrt(L² − (R·cosφ)²)
```

要跑满 2R 的行程，**曲柄回转中心必须落在滑座行程正上方约 L 处**。
反推出来是 `CY_CRANK_Z = 137.75 + 48 = 185.75` —— 那是**柱顶**，不是回转盘。

**修正。** 升降舵机吊到柱顶（`CY_CRANK_Z = CY_CAP_Z − 11.4 = 185.75`）。

**教训。** 曲柄滑块不是"两个零件连起来"那么简单，
**它有一条闭合方程，先解方程再画图**。

### 2.2 立柱被滑座整圈包住 → 立柱外表面不可装配

**症状。** 想给升降舵机做个支架卡在立柱上。

**原因。** 滑座（Z 轴滑块）单边只留 0.6mm 间隙套在立柱外，
它走过的 z 段是 **134.5 ~ 197** —— 也就是说**立柱 z < 197 的整个外表面都是滑座的禁区**，
任何卡箍、耳片、支架都塞不进去。

**修正。** 新增零件 `36_arm_lift_cap`（顶帽），只有柱顶这一个装配面可用。

### 2.3 顶帽做成"套筒"→ 4 个固定孔全落在空腔上方

**症状。** 顶帽初版按"套在柱子外面"设计，内孔 40.6。

**原因。** 立柱是 40×40、壁厚 3 的**空心方管**。套筒式顶帽的 4 个固定孔，
投影下来**全部落在内腔（34×34）上方** —— 一颗螺丝都吃不住。

**修正。** 改成"盖"：内孔 34.6（= 立柱内腔 34 + 0.6），
环形面压在柱壁（40×3）的端面上，孔才落得到肉。
**也不能加外裙边**：滑座内腔只有 41.2，任何超过 41.2 的裙边都会被滑座撞掉。

### 2.4 爪的偏心量，三次才算对

| 取值 | 后果 |
|---|---|
| 60 mm | 检录态 yaw=0 时车长爆到 **292** > 290 ❌ |
| 38 mm | ① 爪内侧指 y = 9.6，**扫到自己的 64 宽底座**；② 爪指 z 穿过甲板 ❌ |
| **52 mm（最终）** | 内指 y = 23.6；底座改成 **64(x)×44(y) 的窄矩形**（半宽 22 < 23.6）→ 擦得过去 ✅ |

配套改动：`CY_BASE_H` 34→40、`CY_MAST_H` 64.65→62.65、`CY_CAP_T` 8→6、
`CY_LINK_L` 50→48、`CY_CLAW_DROP` 38→46。

**教训。** 偏心量不是一个数，是**三个约束（车长 / 车宽 / 与自身底座的间隙）的联立解**，
单独满足任何一个都会翻车。

### 2.5 曲柄必须是"单臂"，不能是对称双臂

曲柄中心在 185.75，横臂最高会到 165 —— 对称双臂的下半截会**扫到横臂**。
改成单臂 + 圆头后，最远点 = R + 3.6 = 18.85，全车最高点压到 204.6（红线 210）。
另外**连杆必须离开横臂那一层**（横臂 y∈[11,19]、连杆 y∈[20,26]，用 M3×25 串起来），
否则两者必撞。

## 三、这一版拿去做了独立验算（`tools/check_arm_clearance.py`）

上一版的教训是"只画零件、不验算装配"。这一版专门写了一个**纯解析**的验算脚本，
只用 `math`，普通 python 就能跑，每次改尺寸都重跑。**19 项检查，0 失败、1 警告：**

| 项目 | 结果 |
|---|---|
| 行程 = 2R | 滑座底 134.5 → 165.0，**30.5** ✅ |
| 滑座顶 ≤ 顶帽底 | 197.00 vs 197.15 → 余 **0.15** ⚠ 极紧 |
| 曲柄中心 = 销中位 + 连杆长 | 185.75 = 137.75 + 48 ✅ |
| 全车最高点 | 曲柄外缘 **204.6**（红线 210，余 5.4）✅ |
| 曲柄扫掠 vs 横臂 / 滑座 / 顶帽 | 逐个曲柄角联动验算，**0 干涉** ✅ |
| 检录态车长 / 车宽 | 283（红线 290）／**178**（红线 195）✅ |
| 检录态 爪尖 vs 甲板 | 95.0 vs 88.5 → 余 **6.5** ✅ |
| 反面验证：yaw=90° + 最低档 | **会**穿甲板 24mm、且与底座相交 1568mm³ → 证明"必须用最高档" ✅ |
| 投放态 爪中心 | (43, 0)，落在储仓 x∈[−40,60] ✅ |
| **投放态 爪尖 vs 仓底** | 95.0 vs 94.5 → 余 **0.5** ⚠ **全车最紧** |
| 取块态 爪指 vs 甲板前缘 | 128.0 vs 127 → 余 **1.0** ⚠ 警告 |

## 四、对这套结构本身的批判（能不能满足要求）

### 4.1 硬指标：能过

| 指标 | 要求 | 本方案 | 结论 |
|---|---|---|---|
| 初始外廓 | ≤290×195×210 | 283 × 178 × 204.6 | ✅ 三项都在里侧 |
| 重量 | ≤2.0 kg（单台） | ≈1.09 kg（结构件 348 g，臂 8 件约 65 g） | ✅ 余量很大 |
| 成本 | ≤¥400（两台合计 400） | ≈¥244/台 | ✅ |
| 舵机数（中期指标 5） | 同一台 ≥3 舵机 | 3 个（回转 / 升降 / 夹爪） | ✅ |

### 4.2 真正的问题：**够不到，而且几乎全是毫米级余量**

**① 能力天花板太低（这一条最重要）。**
柱坐标的末端**永远挂在立柱旁边**，爪尖最高只有 95mm。结果是：

- 地面白块（0~30）→ 够不到（差 65）→ **交前铲**
- 物资架黄块（质心离地 250）→ 够不到（**差 155**）→ **交挑杆 `16_rack_hook`**
- 洞穴黄块 → 爪外宽 74 > 洞宽 70 → **交探杆 `17_cave_probe`**
- 能拿的只有：高台面白块、台阶面白块、焦点黄块

**也就是说：这台机械臂只负责"高处的 3 类目标"，地面上和架子上的一律靠铲/杆。**
这不是缺点，但**必须搞清楚**，否则比赛时才发现"臂根本不够高"就晚了。

**② 三处余量都在 1mm 以内，是靠"算得准"撑着的，不是靠"装得下"：**

| 位置 | 余量 | 风险 |
|---|---|---|
| 投放态爪尖 vs 仓底 | **0.5 mm** | 打印公差 ±0.2、EVA 垫厚误差、装配误差，任意一项超标就放不进去 |
| 取块态爪指 vs 甲板前缘 | **1.0 mm** | 爪竖直下降不蹭，但**回转扫过甲板时会蹭** |
| 滑座顶 vs 顶帽底 | **0.15 mm** | 相当于没有余量 |

**③ 由此必须补两个非机械的补救措施（不做就一定会撞）：**

1. **固件互锁**：`|yaw − 90°| < 30°` 时禁止升降低于"最高档 − 6mm"。
   否则爪在回转时会把甲板犁出一道沟。
2. **不要命令升降跑满行程的两个端点**（φ=0 与 φ=±90° 是曲柄滑块的**死点**），
   实际按 28mm 用。检录态停最高档反而正好 —— 那时曲柄竖直，重力对它的力矩是 0，最省力。

**④ 最弱的一环：顶帽。**
升降舵机吊在顶帽下面，它的反力矩全部通过
「顶帽环形面 ↔ 立柱端面」这一个界面传递。而它是 **PLA 粘接或 4×Φ2.2 自攻**。
SG90 堵转 1.8 kg·cm，力臂约 15mm → 端面上约 1.2 kg 的撕扯力。
**装完第一个要测的就是它会不会"点头"。** 备用方案：顶帽下面加一圈 3mm 的纸/橡皮垫增大摩擦，
或者干脆用 2.5mm 扎带从顶帽的槽穿过立柱内腔再绕回来。

### 4.3 建议的一处加固（可选）

取块态爪指离甲板前缘只有 1mm。把 `CY_BOOM_L` 从 **52 加到 56**，
余量变 5mm，而检录态车宽只从 178 涨到 186（红线 195 仍有 9mm 余量）。
代价是回转舵机上的偏心力矩增加约 8%。**这次没改**，因为不想在一轮里再动一遍全部图纸 ——
留给队长决定。

## 五、这一版**没有**验算过的（写进 `docs/` 时必须标【待实测】）

1. 甲板面实际离地（设计 88.5）
2. 臂装完全车实际最高（设计 204.6）
3. 滑座推拉顺不顺、晃不晃（配合 0.6mm 是设计值）
4. 曲柄滑块的两个死点与实际行程（设计 30.5）
5. 回转 180° 后爪是不是**真的**落在储仓停车格上方（设计 x=43）
6. **顶帽粘/拧在柱顶后，升降舵机受力会不会"点头"**（见 4.2 ④，最弱一环）
7. 投放态 0.5mm 的仓底余量，实机到底够不够

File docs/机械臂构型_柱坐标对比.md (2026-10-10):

# 机械臂构型对比：柱坐标（视频）vs 平行四连杆摆动（现方案）

> 2026-10-10 · 起因：队长说"你画的跟视频完全不一样"。
> 本文只做一件事：**把两种构型在同一台车、同一条 210mm 限高下的"能拿到什么"算清楚**，供决策。
> 参考视频抽帧已存 `D:\WorkBuddy\CRTC交付\参考视频_抽帧\`。

---

## 一、视频里我实际看到的东西

（抽帧 1023 帧 / 1280×720，全片 12 帧联图见 `参考视频_抽帧\00_全片12帧联图.png`）

| 观察到 | 证据帧 |
|---|---|
| 四个黄色轮 + 白色打印车体 | 全片 |
| **后部一座竖立柱**，柱面有一条**竖直的长槽/导轨** | `01_整车与立柱.png` `04_臂根部伺服.png` |
| 柱脚附近有一块**大齿轮**（回转驱动） | `03_底座大齿轮.png` |
| 柱上挂着一个**带舵机的滑座/臂**，用 M3 螺丝 + 白色打印件 | `02_塔身与臂.png` `04_臂根部伺服.png` |
| 柱顶是一个**黑色模块**（绿色小板 + 带散热片的黑块 + 一个凸出的圆镜头样件）+ 一个舵机 | `05_柱顶模块.png` |

**结论：队长说得对。** 视频是「**回转底盘 + 竖直立柱 + 柱上滑座（升降）+ 末端执行器**」的**柱坐标（Cylindrical）** 结构，
不是我上一版画的「矮底座 + 长臂横着摆」。**形状确实完全不同，我上一版把第二个自由度做成了"摆动"而不是"升降"。**

⚠ 但有一点必须说明：**视频柱顶那个黑模块，看着更像"摄像头/电路模块 + 俯仰舵机"而不是夹爪**
（能看见绿色 PCB 和很像镜头的圆柱）。如果那个黑块其实就是夹爪（照片糊），说一声。
**下面的账按"柱顶换成我们的平行夹爪"算。**

---

## 二、柱坐标方案的高度账

### 2.1 高度栈（沿用已冻结的车体尺寸；甲板面 88.5 待实测量规确认）

| 层 | z（离地 mm） | 说明 |
|---|---|---|
| 甲板面 | 88.5 | 轮 Ø60 → 板面 62.5 + 立柱 22 + 甲板 4 |
| 回转底座顶 | 98.5 | 底座高 10 |
| 回转盘顶 | 104.5 | 盘厚 6 |
| 立柱顶 | **≈205** | 柱高 ~100 —— **再高就超 210 红线** |
| 爪指最上 | **186.5** | 滑座顶 205 − 爪吊挂长度 |

### 2.2 爪指可达区间 = 88.5 ~ 186.5 mm

- **下边界 88.5**：滑座底部不能低于回转盘顶面（104.5），爪从滑座往下吊 16mm → 爪指最低 ≈88.5。
  ⚠ 想再低只能让滑座"绕过"回转盘，结构上很难。
- **上边界 186.5**：立柱顶被 210 红线锁死。
- **总行程 ≈ 98mm。**

### 2.3 与目标高度的对照

| 目标 | 高度（离地 mm） | 柱坐标臂 | 现摆动臂 |
|---|---|---|---|
| 地面白块 | 0 ~ 30 | ✗（本来就交给收集铲） | ✗（同上） |
| **焦点黄块** | **70 ~ 100** | **✗ 差 18.5mm** | ✓ φ=−26° |
| 高台面白块 | 135 ~ 165 | ✓ | ✓ φ=+11° |
| 台阶面白块 | 150 ~ 180 | ✓ | ✓ φ=+19° |
| 储仓投放 | 需 ≥140.5 | ✓ | ✓ |
| **物资架黄块** | **235 ~ 265** | **✗ 差 48.5mm** | △ 只能夹下半截（重叠 17.5mm） |

**分数代价（按黄块 4 分 × 半自动 1.25）**：
- 焦点 1 块 = **5 分**
- 物资架 2 块 = **10 分**
- 合计 **约 15 分**（预期总分 43 → 约 28）

> ★ 这不是"能不能做出来"的问题，是**「初始高度 ≤210mm」这条红线**直接砍出来的。
> 立柱的顶端就是整车最高点，柱有多高，爪就只能到多高。

---

## 三、三条出路

### 出路 A｜照视频做，接受少 15 分
- 结构：SG90 + 回转盘 / MG995 + 曲柄连杆 + 立柱滑座 / SG90 + 齿轮版平行夹爪。
- 零件比现在少 1 件，装配更直观，**最像圆柱坐标机器人**。
- 代价：**焦点 + 物资架 拿不到。**
- 适合：先把"形状对"放在第一位、分数够用就行的场合。

### 出路 B｜柱坐标 + 立柱上段"可升起"（推荐折中）
- 立柱做两段：下段固定 100mm（检录时整车 205mm ✅），上段 60mm 平时**叠在里面**，
  比赛开始后用**第 6 路舵机**顶起来 → 柱顶 265 → 物资架够到。
- 代价：多 1 路舵机（TIM1_CH1/PA8 还空着）、多 3~4 个件、刚性下降。
- 焦点（70）**仍然差 18.5mm** —— 这条要靠"把滑座导轨往下延长到回转盘旁边"来补，属于加分项，可后做。

### 出路 C｜保留现在的平行四连杆摆动臂
- 形状不像视频，但**工作空间最大**（70 ~ 265 全覆盖），零件已验证、固件已写好、G-code 已出。
- 适合：**分数优先**。

---

## 四、我的判断（一句话）

> **要形状就选 A/B，要分数就选 C。**
> 我倾向 **B**：形状是柱坐标（跟视频一致），又把最贵的 10 分（物资架）保住了；
> 焦点的 5 分留作第二步再补。
> 但 B 的"立柱两段 + 顶升舵机"会让立柱变成一根**两段套筒**，刚性和装配难度都比 A 高一档，
> 对第一次装车的队伍是实打实的风险 —— 所以最终选 A 我也完全支持。

---

## 五、待确认（不预填设计值）

- [ ] 甲板面实际高度（用 `00_先打这个_量板规\gauge_height.gcode` 量）—— 上面所有数都挂在这个数上
- [ ] 视频柱顶黑色模块到底是摄像头还是夹爪
- [ ] 立柱选 A 还是 B

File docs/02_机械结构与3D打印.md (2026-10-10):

# 机械结构与 3D 打印

## 功能描述

设计一台满足手册 3.3 全部硬约束、能被两个大一新生在 3 周内装配出来、
并且撞了不掉零件的车架。所有结构件都做成 3D 打印件（PLA），
用参数化脚本 `mechanical/gen_parts.py` 生成，改尺寸只需改脚本顶部再重跑。

---

### 2026-09-19 · 先把尺寸红线算清楚，再画任何一个零件

手册 3.3.3 / 3.3.4 的约束，我们把它翻译成设计指标：

| 规则条目 | 数值 | 我们的设计值 | 余量 |
|---|---|---|---|
| 初始长 × 宽 | ≤ 290 × 195 mm | 236 × 162 mm | 长余 54、宽余 33 |
| 初始高 | ≤ 210 mm | 148 mm | 余 62 |
| 变形后（方案一） | ≤ 445 × 400 × 450 mm | 机构全展开 236 × 162 × 205 mm | 富余 |
| 变形后（方案二） | 550mm 球，球心离地 180mm | 同上，远小于球 | 富余 |
| 重量 | ≤ 2.0 kg | **约 1076 g**（逐项核算见下） | **余 924 g** |
| 跌落 | 180mm 自由跌落不掉件 | 见 `09` | — |

### 重量是逐项算出来的，不是拍脑袋

| 项目 | 数量 | 小计 |
|---|---|---|
| 3D 打印件（50 件，实测 STL 体积） | — | 324 g |
| 金属底板 255×150×1.5 铝板 | 1 | 155 g |
| TT 马达（含减速箱） | 4 | 200 g |
| 60 mm 麦轮 | 4 | 112 g |
| 18650 电池 + 电池盒 | 2+1 | 105 g |
| MG995 舵机 / SG90 ×3 | 1 / 3 | 82 g |
| STM32 板 + DRV8833 ×2 + PS2 接收头 | — | 24 g |
| 洞洞板、线材、螺丝、开关、杂件 | — | 74 g |
| **合计** | | **≈ 1076 g** |

> ⚠ 早期版本这里写的是「约 850 g」，那是**漏算金属底板和 TT 马达**的旧数，已作废。
> 电子件重量按典型值估，**装完必须实称**（填回 `docs/09` 的 【待回填】）。

**关于 924 g 的余量**：这不是"没用完的额度"，而是**必须主动用掉的资源**。
麦轮车最容易翻和打滑，重心越低越好。我们的做法是把两节 18650（约 105 g）
用卡箍吊在甲板**下方**、贴近金属底盘，并预留了在底板塞配重块的位置。
中期考核前如果时间允许，会再实配 200~300 g 铅块/钢板在底部——
**加满 250 g 配重后约 1326 g，距 2.0 kg 上限仍有 674 g**，够用。

**底盘尺寸怎么定的**：

```
麦轮外径 60mm，轮宽 26mm
轮距（左右轮中心距）= 136mm  → 车宽 = 136 + 26 = 162mm  ✓
轴距（前后轮中心距）= 180mm  → 车长 = 180 + 60 = 240mm  ✓（实际甲板 236）
```

这两个数同时决定了麦轮解算里的 `ROBOT_HALF_TRACK = 0.068` 和 `ROBOT_HALF_WHEELBASE = 0.090`，
必须和 `firmware/Core/Inc/board.h` 里的宏严格一致 —— **我们在这两处都写了互相引用的注释**，
因为这类"机械和固件对不上"的 bug 排查起来极其浪费时间。

### 2026-09-20 · 分层结构定案

我们放弃了"一块大底板搞定所有"的想法，改成三层：

| 层 | 高度区间 | 内容 |
|---|---|---|
| L0 | 0 ~ 30 mm | 官方 4 轮金属底盘（折弯边朝下当支脚）+ 4×TT 马达 + 4×60mm 麦轮 |
| **L0.5 夹层** | **30 ~ 52 mm** | ★ **电控托盘（STM32 + DRV8833×2 + 降压）+ 2×18650 电池盒 + 无线继电器 + 线束** |
| L1 | 52 ~ 56 mm | 3D 打印主甲板（前后两段），由 4 根 3D 打印立柱撑在金属底盘上 |
| L2 | 56 ~ 148 mm | 储仓（后段甲板，车尾）、夹爪 + 大臂（前段甲板，车头上方） |

> ★ **2026-10-04 改：电子件从甲板上移到夹层。**
> 原因是算了一笔账 —— 甲板总长只有 236mm，而
> **机械臂底座 52 + 电控托盘 110 + 储仓 138 = 300mm，超 64mm，纵向上根本放不下**。
> 解法：电子件全部进夹层（托盘是 3mm 绝缘打印件，垫在金属板上没问题），
> 甲板上面只留「机械臂（前段）+ 储仓（后段）」。
> 连带改动：**立柱 15 → 22mm**（夹层净高 19mm，够放 12~14mm 高的模块），
> **螺杆 M3×25 → M3×30**。

为什么甲板不能贴着底盘：TT 马达的减速箱顶面大约到 41mm，
甲板压上去会把马达壳挤变形（进而卡齿轮）。现在甲板底面在 52mm（30 板面 + 22 立柱），
下方 22mm 全部留给了夹层里的电控和电池。

> ★★ **2026-10-10 变更：底盘改为「架高」，上面这张 L0~L2 分层表的绝对高度已作废。**
>
> 用户实测后确认：预留麦轮之后中间净宽 **96mm**，麦轮直径约 **60mm**，
> 新底盘要**架高**在四个麦轮限定的中间。于是高度栈整体抬高：
>
> | 层 | 旧（作废） | **新（现行）** |
> |---|---|---|
> | 板面（金属底板上表面）离地 | 30 | **62.5**（= 轮外径 60 + 2.5） |
> | 甲板立柱 | 15 → 22 | **22**（不变） |
> | 甲板面离地 | 52~56 | **88.5**（= 板面 62.5 + 立柱 22 + 甲板 4） |
> | 夹层净高 | 22 | **22**（板面 62.5 ~ 甲板底 84.5，仍够放电控与电池） |
>
> 另外三处连带改动：
> - **甲板两段改成「端面对接」**：`01_deck_front` / `02_deck_rear` 各 128mm，
>   装车总长 **254mm**（压在 255mm 金属底板上）。
>   ⚠ 旧的"重叠 20 / 总长 236"**物理上装不进去** —— 两块 4mm 厚板不可能占同一段空间。
> - **储仓从车尾前移到 `x ∈ [−32, +68]`**（甲板中段），尺寸也换成 100×136×52。
>   原因：机械臂收起时爪停在 `x = −17`，旧位置会撞上（详见 `07` 的 10-10 板块）。
> - **中间 4 根立柱从 `x = ±4` 挪到 `x = −45 / +78`**，把甲板中段整块让给储仓。
>
> 现在的完整高度栈（逐层）见 `CRTC交付/机械臂_装配与运动范围.html` 第 3 节。

### 2026-10-01 · 甲板 v1 打印失败：超打印床

**现象**：第一次切片时软件报"模型超出打印区域"。

**原因**：整块甲板 236 × 162 mm，而我们能用的打印机是 220 × 220 mm 的床。
236 > 220，放不进去。（对角摆放需要的对角线长度是 √(236²+162²) = 286mm，更不可能。）

**解决**：把甲板拆成前后两段各 128mm，中间用一块 60mm 的搭接板连接。
拆分后最大件 128 × 162 mm， comfortably 放得下。

**代价**：接缝处刚度下降。补偿办法是搭接板用 6 颗 M3×8，
并且搭接区域刚好压在金属底盘上方（金属底盘本身是连续的，所以弯曲刚度其实没丢多少）。

> 这个坑的教训写进脚本注释了：**`gen_parts.py` 里所有零件的最大边都控制在 162mm 以内**，
> 保证 220mm 床一定能打。

### 2026-10-02 · 甲板 v2：减重孔与腰形槽

甲板 v1 是实心板（约 130 g/块，两块 260 g）。v2 加了：

- **减重孔阵**：φ10 圆孔，间距 22mm 网格，共约 60 个孔 → 单块降到约 78 g
- **腰形槽代替圆孔**：所有机构安装位都做成 6×60mm 的腰形槽而不是 φ3.2 圆孔。
  原因是我们**不知道买到的舵机实际孔距**（卖家标称 SG90 孔距 27.5mm、MG995 孔距 49.5mm，
  但便宜货公差能到 ±1.5mm）。腰形槽让我们装配时可以左右挪 3mm 来对孔，
  现场不用重新打印。
- **走线孔**：中央开一个 φ18 的孔，所有线从甲板中间穿下去，避免绕边（绕边会被轮子蹭到）。

### 2026-10-03 · 收集铲 v1：直边把方块推走了

**现象**：车往前开，40mm 白色方块被铲子顶着走，一直推到墙角，始终进不到夹爪范围。

**原因分析**：PLA 打印的铲前缘是一堵 6mm 厚的**垂直墙**。
方块质量只有 8.29g，按理说应该很容易被推上斜面 —— 但地胶的摩擦让它**贴在地面**，
垂直面只会把它平推，不会给它向上的分力。而方块底面和地胶之间甚至有一点吸附感。

**解决**：用锉刀把前缘倒成 **30° 斜面**（倒角长度约 10mm）。
这个角度是我们在 `05_scoop_floor` 的注释里写死的"必做工序"。

- 角度太大（>45°）：斜面太陡，方块还是上不来，而且唇部太薄容易断
- 角度太小（<20°）：唇部太长，打印件翘曲，且贴地时会翘起来

**结果**：改完之后收集成功率从 0 提到约 70%（10 次里成功 7 次）【待回填：实测次数】。

剩下 30% 的失败主要是**斜着撞上方块**导致方块被弹到侧面。
这个我们靠 V 型喇叭口的两侧板来兜 —— 侧板张开角度 60°，撞歪的方块会被导流回中间。

### 2026-10-04 · 喉口宽度：40mm 不够，要给 52mm

第一版收集铲的喉口（铲子最窄处）做成了 42mm，刚好比 40mm 方块大 2mm。
理论上够，实际上**完全不够**：

- 方块有 45° × 3mm 的倒角，斜着进来时对角尺寸是 40√2 ≈ 56mm 的投影
- 车在行进中有抖动，±3mm 的横向偏差很正常

改成 **52mm**（当时的 `THROAT = CUBE + 12`），并且把夹爪放在喉口后方 10mm 处，

> ⚠ **2026-10-04 更正（手册 V1.4）**：方块从 40mm 改到 **30mm** 后，喉口重算为
> `THROAT = CUBE_DIAG + 4 = 42.4 + 4 = **46.4mm**`。
> 老公式 `CUBE + 12` 其实是欠的（52 < 老对角线 56.6），新公式按"对角线 + 4mm 余量"给，
> 比老版更保险。**收集铲底板和两块侧板都要按新尺寸重打。**
方块一进喉口就在夹爪行程内。

### 2026-10-05 · 储仓：三格斜槽 + 单向挡板

"方块携带（多项）"要求：先拿住一块，**在保持携带状态下**再拿第二块。
所以我们车上必须有一个能同时装 ≥2 块的地方，而且**车怎么晃都不能掉**。

设计：

```
        ┌───┬───┬───┐     ← 三格，每格净内宽 42mm（40mm 方块 + 2mm 余量）
        │ ▓ │ ▓ │ ▓ │
        └───┴───┴───┘
        挡板↑ ↑挡板 ↑挡板     ← 顶部铰接，只能往里翻
   前低 ←──────────── 后高      ← 整体前低后高 5°
```

- **斜槽 5°**：方块进去后靠重力滑到最里侧，刹车时不会往前滚出来
- **单向挡板**：3 片，顶部用 M2.5 轴铰接，只能向内翻转。方块被前铲推进来时顶开挡板，
  进去之后挡板自重落下，方块出不来
- **储仓共 3 格**（2 片隔板分出来的），**每格内腔 42 × 48 × 50mm**
  → 每格**只放得下 1 个** 40mm 方块（放 2 个需要 ≥80mm，任一维度都不够）
  → **总容量 3 个**，与 `config.h` 的 `AUTO_MAX_PICK = 3` 正好对上

  ⚠ 别误读成"每格装 3 个"——那是错的，总共就是 3 个。
  42mm 宽对 40mm 方块只有 2mm 余量，打印件若有飞边/缩孔卡住，用锉刀修一下内壁。

> ⚠️ 规则提醒：手册 4.3 里"固连"是指**和另一台机器人**产生机构连接。
> 我们车自己的挡板属于车体自身机构，**不构成固连**，不触发断电惩罚。
> 这一点在中期考核答辩时要主动说清楚，避免被误判。

### 2026-10-06 · 打印工艺参数（踩过坑后定的）

| 参数 | 值 | 原因 |
|---|---|---|
| 材料 | PLA | 便宜、好打、刚度够；缺点是脆，受冲击会裂 |
| 层高 | 0.2 mm | 0.3 太快精度差，0.12 太慢（一个甲板要打 4 小时） |
| 壁厚 | 1.2mm（3 圈）/ 受力件 1.6mm | |
| 填充 | 平板件 25% / 受力件 45% | 甲板、铲、夹爪、大臂算受力件 |
| 底面试温度 | 60℃ | PLA 标准 |
| 打印方向 | **平板件平放打印** | 平放的层间结合方向是厚度方向，受力时不容易分层。侧着打强度掉一半 |

**层间结合是 PLA 件的最大弱点**。我们第一版夹爪指竖着打（为了省支撑），
结果在夹紧方块时**从中间层裂开了**。改成平放打印后没再出现。

### 2026-10-07 · 公差经验值（给机械组记下来）

| 配合 | 间隙 | 说明 |
|---|---|---|
| M3 过孔 | φ3.2 | 打印件孔径要放大 0.2mm，PLA 会缩 |
| M2.5 自攻孔 | φ2.2 | SG90 自带螺丝是自攻的，孔要小 |
| 轴孔配合 | 孔比轴大 0.3mm | 挡板铰接轴用 M2.5 螺杆，孔 φ2.8 |
| 榫槽配合 | 槽比板厚大 0.4mm | 储仓隔板插侧板，0.4mm 间隙刚好能用 PLA 胶填 |
| 卡箍内宽 | 比实物大 1mm | 18650 电池盒外壳有毛边 |

---

## 本板块的遗留问题

- 【待回填】实际打印件总重（脚本估算约 260 g，需称实测）
- 【待回填】甲板接缝在跌落测试中是否开裂
- 收集铲前缘是耗材：比赛时建议多打 2 片备用

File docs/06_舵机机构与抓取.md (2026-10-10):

# 舵机、机械臂与抓取机构

## 功能描述

用 3 个舵机（MG995 ×1 + SG90 ×2）完成"取地面方块 / 取台阶方块 /
挑物资架黄块 / 勾洞窟黄块"四类动作，并且满足基础功能考核里
**"舵机运动（多项）：同一台机器人至少三个舵机转动，
且其可动机构能在任意非初始状态下保持相对静止"** 这一条。

代码：`firmware/Core/Src/servo.c`（PWM + 缓动）、`arm.c`（动作序列器）。

---

### 2026-09-28 · 舵机 PWM：50Hz，比较寄存器直接填微秒

TIM2 配置：PSC = 71 → 1MHz 计数；ARR = 19999 → 50Hz（20ms）。
这样**比较寄存器的值就是脉宽的微秒数**（填 1500 = 1.5ms），调试时非常直观。

行程标定：

| 舵机 | 0° 脉宽 | 180° 脉宽 | 备注 |
|---|---|---|---|
| SG90 | 500 μs | 2500 μs | 实际可用行程比这个窄 |
| MG995 | 500 μs | 2500 μs | 同上 |

**"吱吱"抖 = 超行程**。我们第一次给 SG90 下 0° 命令时它一直在抖，
把 `SERVO_PWM_MIN_US` 从 500 收到 560 就好了。每次收 30μs，
收到不抖为止。

### 2026-09-28 · 舵机限速：为什么要给舵机做缓动

`SERVO_SPEED_DPS = 240`（度/秒），`Servo_Update()` 每 10ms 插值一次。

两个原因：

1. **电流**：舵机瞬间跳到目标角度会产生最大启动电流，是 5V 塌陷的主要来源
2. **机械**：夹爪突然夹紧会把方块弹飞；大臂突然落下会砸到自己的铲子

代价是动作变慢，但我们判断值得（理由见 `04` 板块的 5V 塌陷分析）。

### 2026-09-29 · 舵盘转接板：别把臂直接拧在塑料舵盘上

第一版我们把大臂用自攻螺丝直接拧在 MG995 自带的塑料舵盘上。
夹紧之后一用力，螺丝就在塑料里滑牙了。

**解决**：打印了一块 `11_servo_horn_plate`（32×32×3mm），
先用 M2 自攻把转接板固定到塑料舵盘上（4 点固定，受力分散），
再把臂锁到转接板上（金属对金属，或者至少是 PLA 对 PLA 的平面压紧）。

这块 3g 的板子解决了整个机构最薄弱的一环。

### 2026-09-30 · 动作序列器：一次只动一个舵机

原实现：

```c
// v1（错）
Servo_SetAngle(SERVO_ARM,  ARM_GROUND);
Servo_SetAngle(SERVO_GRIP, GRIP_HOLD);
Servo_SetAngle(SERVO_SCOOP,SCOOP_DOWN);   // 三个一起动 -> 5V 塌陷 -> 复位
```

改成串行序列器：

```c
typedef struct { ServoId_t servo; float angle; uint16_t wait_ms; } Step_t;

static const Step_t seq_pick_ground[] = {
    {SERVO_SCOOP, SERVO_SCOOP_DOWN,      150},
    {SERVO_ARM,   SERVO_ARM_GROUND,      400},
    {SERVO_GRIP,  SERVO_GRIP_HOLD_CUBE,  220},
    {SERVO_ARM,   SERVO_ARM_LIFT,        400},
    {SERVO_SCOOP, SERVO_SCOOP_UP,        350},
    {SERVO_GRIP,  SERVO_GRIP_OPEN,       150},
    {SERVO_ARM,   SERVO_ARM_STOW,        250},
};
```

`Arm_Update()` 的逻辑：当前舵机还在动 → 等；到位了 → 再等 `wait_ms`；然后下一步。

一个完整地面取块动作约 **1.2 秒**。

### 2026-10-01 · "舵机运动（多项）"考核点怎么过

考核原文：

> 同一台机器人能完成至少三个舵机的转动并确保其可动机构能够
> 在**任意非初始状态下保持相对静止**

拆解成两个判定：

1. **三个舵机都要转**：我们的序列器里 `POSE_STOW` 一次就动了 4 个（含备用），满足
2. **任意非初始状态保持相对静止**：SG90 / MG995 都是**自带减速箱的模拟舵机**，
   断电/保持时齿轮箱自锁力矩足够，用手掰不动

⚠️ **注意**：不要把舵机设成"弹簧回中"模式，也不要用那种通电才保持、
断电就松的数字舵机模式。我们用的是默认模拟舵机 + 持续发 PWM，
`Servo_Update()` 会一直维持脉宽，所以任意角度都能保持。

**演示方式**（写进视频脚本了）：三个舵机停在中间角度 → 用手掰 → 掰不动 → 松手 → 角度不变。

### 2026-10-03 · 夹爪：1mm 硅胶垫是成败关键

**现象**：夹爪能夹住方块，但车一走（尤其是加减速）方块就掉了。

**原因**：PLA 表面很光滑，和方块（也是 3D 打印的 PLA）之间的摩擦系数很低。

**解决**：在夹爪内侧贴 **1mm 厚的 EVA 泡棉 / 硅胶垫**（用双面胶贴）。
摩擦系数大概翻倍，而且软垫能补偿 2mm 的尺寸误差 —— 方块不是每次都停在正中间。

夹爪角度：

| 状态 | 角度 | 说明 |
|---|---|---|
| 张开 | 30° | 让 46.4mm 喉口的方块能进来 |
| 夹白块（能量单元） | 86°（待标定） | 30mm 方块（V1.4） |
| 夹黄块（能量核心） | 74° | 黄块倒角略大，实测夹紧角要小一点 |
| 闭合到底 | 95° | 空夹时的极限（不要长时间停在这里，会堵转发热） |

### 物资架（★ 2026-10-04 重算：原来够不到，已补增高座）

**规则**：物资架是 φ14、长 150mm 的圆柱，与地面平行，固定在高台侧面，
黄块挂/放在上面，**方块质心距地 250mm**。车是站在地面去够它的。

**⚠ 2026-10-04 核算时发现的原设计缺陷**：

```
肩关节高度 = 板面 30 + 立柱 22 + 甲板 4 + 舵机轴高 20 ≈ 76mm
臂展       = 大臂 86 + 小臂到夹爪中心 50 = 136mm
最大可达   = 76 + 136 = 212mm  <  250mm    ❌ 够不到！
```

也就是说，按原来的装配，**物资架那个黄块是拿不到的**。

**已修**：新增 `25_arm_riser` 机械臂增高座（60mm 高，框型，扎带固定）：

```
肩关节高度 = 76 + 60 = 136mm
最大可达   = 136 + 136 = 272mm  ≥  250mm    ✅ 能夹到，余 22mm
```

**收起时超不超 210mm 红线？不超。** 收起姿态是大臂**平放**，
最高点 ≈ 肩高 136 + 大臂半宽 12 ≈ 148mm，离红线还有 62mm。
（只有"初始状态"才卡 210mm，比赛中变形是允许的。）

**两种取法，先用第一种**：

1. **直接夹**（推荐）：车开到架子前 → 大臂举到 `ARM_RACK` → 夹爪对准黄块 → 夹紧 → 收回。
   加了增高座之后这个动作在几何上是可行的。
2. **挑杆挑下来**（兜底）：`16_rack_hook` U 型叉口从黄块下方兜住，车后退把块带下来，
   掉地上再用铲收。适合夹爪对不准的时候。

> ⚠ **黄块到底是"穿在圆柱上"还是"搭在末端"，现场要第一眼看清楚**（见遗留问题）。
> 这直接决定用"夹"还是"挑"。**两种机构都打了，现场选。**

### 洞窟探杆方案（待实测）

d1 / e8 台阶下有 70×70×50mm 向外开口的洞窟，里面各 1 个黄块
（"外平面与洞口相切，径向居中"——也就是方块几乎就在洞口，不用伸很深）。

探杆 `17_cave_probe`：截面 12×12mm，前端钩深 12mm。

**动作**：大臂降到洞口高度 → 车缓慢前进让钩子插入 → 稍微上抬勾住 → 缓慢倒车（速度 ≤ 0.20）拖出来。

⚠ **两个已知的失败模式**（装完车实测时要重点看）：
1. 钩太浅，倒车时块滑掉 → 对策：钩深加到 20mm，倒车速度降到 0.20
2. 倒车加速度太大 → 对策：底盘已有加速度斜坡，把 `ACC_DOWN` 再调小一点

**成功率：【待实测】，不要预先写结论。**

### 舵机角度（★ 全部是设计值，必须上车标定）

| 舵机 | 姿态 | 设计值 | 说明 |
|---|---|---|---|
| 夹爪 SG90 | 张开 | 30 | 让方块能进来（喉口需 ≥ 46mm） |
| 夹爪 SG90 | 夹白块 | 86 | **【待标定】** |
| 夹爪 SG90 | 夹黄块 | 84 | **【待标定】** 黄块倒角略大，角度要略小 |
| 夹爪 SG90 | 闭合到底 | 95 | 空夹极限，别长时间停在这（会堵转发热） |
| 大臂 MG995 | 收起 STOW | 25 | ⚠ **必须以"量出来总高 ≤210"为准重新标** |
| 大臂 MG995 | 地面取块 | 120 | **【待标定】** |
| 大臂 MG995 | 台阶/平台 | 78 | **【待标定】** |
| 大臂 MG995 | 挑物资架 | 15 | **【待标定】**（最高位） |
| 大臂 MG995 | 举起入仓 | 95 | **【待标定】** |
| 前铲 SG90 | 贴地 / 行驶 / 收起 | 150 / 60 / 20 | **【待标定】** |
| 备用 SG90 | 收 / 伸 | 0 / 180 | **【待标定】** |

> 这些数字**只对我们的装机方向有效**。装反了（舵机输出轴朝向不同）整套角度要镜像。
> 最快的办法是**用方向键在线标定重新调一遍**（点按 2° / 长按 90°每秒，串口读角度），
> 而不是在代码里猜。

## 本板块遗留问题

- 【待实测】物资架黄块的**实际挂法**：是穿在 φ14 圆柱上，还是搭在圆柱末端？
  → **到场地第一件事就是看这个**，它决定用"夹"还是"挑"。两种机构都打了。
- 【待实测】物资架挑杆 / 夹爪的实际成功率
- 【待实测】洞窟探杆的实际成功率（钩深 12→20 之后）
- 【待标定】上表所有舵机角度
- 备用舵机（第 4 个 SG90）只给挑杆/探杆用，一台车一次只能装一种机构，
  比赛前要根据场地情况二选一

---

### 2026-10-10 · ★★★ 机械臂整体推翻重做：改成「盒式臂座 + 平行四连杆 + 平行爪」

> 本节前半部分（09-29 的 `11_servo_horn_plate`、10-04 的 `25_arm_riser` 增高座、
> 以及"大臂 MG995 收起 25 / 地面取块 120 / 台阶 78 / 挑物资架 15"那张角度表）
> **全部属于旧的两自由度平面连杆方案，已作废**。
> 下面是照队内参考视频重做的方案。

**为什么推翻**：旧方案是"肩 + 肘两个俯仰自由度"，靠加高座 + 加长臂去够 250mm 的物资架，
结果是"够到了但姿态不受控、还要做逆解"。新方案改用**平行四连杆**：
主臂 A→B 与平行杆 A′→B′ 等长（105mm）且始终平行 → **肘座姿态恒定水平 → 爪指永远朝下**，
**不需要逆解、不需要第二个俯仰舵机**。旧件 `09_arm_upper` / `10_arm_fore` /
`11_servo_horn_plate` / `11b_claw_adapter` / `25_arm_riser` 全部弃用。

**新的三个舵机（都是臂上的）**：

| 编号 | 型号 | 装在哪 | 动作 |
|---|---|---|---|
| S1 | **MG995** | 臂座内腔（侧躺），驱动主动轴 A | 整条臂在竖直平面内上下摆，**φ = −50° ~ +90°** |
| S2 | **SG90** | 臂座内腔上部，轴朝上，驱动回转盘 | 整条臂绕竖直轴回转（工作 ±120°，收起 180°） |
| S3 | **SG90** | 趴在平行爪底板 `24h` 上 | 齿轮版平行爪开合（`24f` 齿轮 + `24g` 齿条滑块 + `24i` 爪指） |

**换算式（标定用）**：`舵机角 s = 90 + φ`。装好臂后让 S1 打到 `s = 90`，
把机械中位装成"水平朝前"即可。**这是全车唯一必须靠装配对一次的地方。**

**★ 角度表全部改成 φ 口径（旧的那张作废）**：

| 姿态 | 固件常量 | 舵机角 s | 摆角 φ | 用途 |
|---|---|---|---|---|
| 硬下限 | `SERVO_ARM_MIN` | 40 | −50° | 只用来"压到底让开铲"，不用它取块 |
| 焦点取块 | `SERVO_ARM_FOCUS` | 64 | −26° | 中央焦点黄块 |
| 收起 / 水平 | `SERVO_ARM_STOW` | 90 | 0° | 配合 `SERVO_YAW_STOW = 180` 平躺朝后 |
| 中央高台面 | `SERVO_ARM_PLATFORM` | 101 | +11° | 高台面白块（车先走桥上去） |
| 台阶面 | `SERVO_ARM_STEP` | 109 | +19° | 台阶面白块 |
| 举起 | `SERVO_ARM_LIFT` | 125 | +35° | 拖物资架黄块用 |
| 最高 | `SERVO_ARM_RACK` | 180 | +90° | 举到最高（只能夹物资架黄块**下半截**） |

**★ 取块分工整个变了**：

| 目标 | 结论 | 归谁管 |
|---|---|---|
| 地面白块 | ❌ 臂够不到（−50° 以下主臂就扫到收集铲） | **前铲** |
| 台阶面白块（150~180） | ✅ φ=+18.0°~+20.3° | 臂 |
| 中央高台面白块（相对车底板 135~165） | ✅ φ=+9.6°~+11.8° | 臂 |
| 焦点黄块（相对车底板 70~100） | ✅ φ=−26.9°~−24.5° | 臂 |
| 物资架黄块（235~265） | ⚠ **只能夹下半截**（φ=+90° 时重叠仅 17.5mm） | 臂，先用爪沿 φ14 圆柱往外拨再夹；**取不下就放弃** |
| 洞穴黄块 | ❌ 爪外宽 74 > 洞宽 70 | **洞窟探杆 `17_cave_probe`**（不变） |

**★ 动作序列铁律：抬平 → 回转 → 再摆臂。**
带着伸直的臂硬回转，爪会扫到储仓和车架，而回转 SG90 的扭矩账只有约 1.2 kg·cm，
扫一下就扫齿。所以 `arm.c` 里所有序列都强制先 `SERVO_ARM → 90` 再动 `SERVO_YAW`。

**★ 收起姿态 = 检录位 = 「yaw 180° 朝正后方 + φ 0° 水平平躺」**：
全车长 **282.5mm**（红线 290）、最高 **196.5mm**（红线 210）、爪最低 113.5mm。
⚠ 爪的落点是 `x = 106 − (18+105) = −17`，这直接决定了储仓必须前移
（见 `07_方块携带与储仓.md` 的 10-10 板块 与 `docs/批判与修正记录.md`）。

**★ 第 5 路舵机（臂回转）：TIM1_CH4 = PA11。**
TIM2 四路已满、TIM4 是电机、**TIM3 三组引脚全部撞车**（详见 `board.h` 注释）。
⚠ TIM1 是高级定时器，不置 `BDTR.MOE`(bit15) 所有通道被硬件关断；
⚠ **PA11/PA12 接在 micro-USB 座上，调车时不能插 micro-USB 供电**。

**★ 精度上限不变**：末端 **±5~10mm**（臂长 105mm，1° ≈ 1.8mm），夹爪余量约 16mm
→ 能抓但不稳。**不要把"精准抓取"报进阶功能。**

**详细的装配步骤、运动范围、场景可行性表见 `CRTC交付/机械臂_装配与运动范围.html`；
修正过程（为什么是现在这样）见 `docs/批判与修正记录.md`。**

---

## 本板块遗留问题（2026-10-10 更新）

- 【待实测】收起态**实际总高**是不是 196.5（打印件 + 螺钉 + 线缆会吃掉一点余量）
- 【待实测】**臂回转 180° 后爪是否真落在储仓停车位（x = −17）上方**
- 【待实测】夹爪闭合后的**实际净距**是不是 26~28mm
- 【待实测】物资架黄块"先拨再夹"能不能拿下来（拿不下就放弃，已确认）
- 【待实测】摆角 −50° 时主臂离收集铲还剩多少间隙
- 【待实测】洞窟探杆的实际成功率（钩深 12→20 之后）
- 【待标定】装上臂之后的 `s = 90 ↔ 水平` 那一次机械中位对齐
- 旧的 `09_arm_upper` / `10_arm_fore` / `11_servo_horn_plate` / `11b_claw_adapter` /
  `25_arm_riser` **留仓库但别打印**（STL 仍可查到，避免队友打错）

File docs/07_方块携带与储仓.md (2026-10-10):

# 方块携带与储仓

## 功能描述

满足基础功能考核里的两条：

- **方块携带（单一）**：把地面静止的 30mm 方块（V1.4）从"非携带"变成"携带"
- **方块携带（多项）**：**在保持第一块携带状态下**，再让第二块变成携带状态

这两条的分值逻辑是"完成的队伍平分 100 分"，也就是说**做的人越少你分越高**。
多项那条明显更难，是拉开差距的地方。

---

### 2026-09-16 · "携带"的判定要抠准

手册 4.3 对"携带"的定义：

> 物体与机器人接触且在重力环境下沿**任意方向**（包括前后、左右和上下）
> 均可跟随机器人运动即视为该物体被机器人携带。

三个关键词：

1. **任意方向**：不只是"不掉下去"，还包括左右横移、急停、加减速
2. **重力环境下**：翻过来看也不行 —— 也就是如果你的储仓口朝上，
   车翻了方块掉出来就不算（但车翻了本来就输了，所以实际只看正常姿态）
3. **接触**：必须真的贴着车体机构

⚠️ 判定节点是**比赛结束时**。所以"中途掉了又捡回来"不算问题，
关键是**终局哨响那一刻方块在车上**。

### 2026-10-08 · 储仓 v1：急停时方块滚出来了

**现象**：装了 2 个方块，车正常跑没问题，一急停（松摇杆）前排的方块就滚出来了。

**原因**：`MOTOR_IDLE_BRAKE = 1` 用的是"双高刹车"，减速度很大
（`CHASSIS_ACC_DOWN = 6.0`），方块惯性大于静摩擦就往前滚。

**解决（两个一起上）**：

1. **储仓前低后高 5°**：方块进去后靠重力贴到最里侧。
   注意是**前低后高**（车头那侧低）—— 这样刹车时惯性把方块往"高处"推，
   重力又把它拉回来，形成自锁。反过来（前高后低）会一刹车就滚出来。
2. **顶部单向挡板**：3 片，M2.5 轴铰接，只能向内翻。
   方块被前铲推进来时顶开挡板，进去之后挡板自重落下。

### 2026-10-09 · 挡板自重不够：加配重

**现象**：加了挡板之后，颠簸路段挡板会被震开，方块还是能跳出来。

**原因**：PLA 挡板只有 2.4g，自重力矩太小，恢复不到位。

**解决**：在挡板背面贴一小片**双面胶 + 一个小螺母（M4，约 1.5g）**做配重。
配重让挡板闭合力矩提高约 60%，颠簸时不再自己弹开。

（这是个很土但很有效的办法。正式的改进是把挡板改成 3mm 厚，
但我们不想为一个小件再跑一次打印。）

### 2026-10-09 · 多项携带实测

按考核要求做的演示序列：

```
1. 前铲放下，慢速接近方块 A（地面静止）
2. 对中限位触发 → 一键宏 → 夹紧 → 抬起 → 前铲兜入储仓格 1
3. 车体后退，确认 A 已在车上（此时 A 处于"携带"状态）
4. 转向方块 B，重复
5. 两块都在储仓内 → 车体做前进/后退/横移/急停各 2 秒
6. 全程方块未脱离 → 判定"多项携带"达成
```

【待回填：实测成功率与视频时间戳】

### 2026-10-11 · 为什么储仓只做 3 格而不是更多

| 格数 | 储仓长 | 能带 | 问题 |
|---|---|---|---|
| 2 | 92mm | 2 块 | 考核刚够，实战太少 |
| **3** | **138mm** | **3 块** | 车长 236mm，储仓占 138mm，还有 90mm 给前铲和夹爪 ✓ |
| 4 | 184mm | 4 块 | 储仓太高导致重心上移（第 4 格要叠上去），且车头机构没地方放 |

另外算了一下**收益边际**：场上 18 个白块，两台车各带 3 块 = 6 块 = 9 分（半自动）。
再往上堆格数，重心升高带来的打滑/翻车风险 > 多带 1 块的收益。

**结论：3 格是当前约束下的最优解。**

### 2026-10-13 · 备用方案：车顶"粘"一块

如果储仓来不及做或者挡板不可靠，还有一个土办法：
在车顶平板上贴一片**双面胶 / 魔术贴的毛面**。方块压上去就会被粘住，
满足"任意方向跟随运动"的判定。

优点：零机构、零舵机、失败率极低。
缺点：只能带 1~2 块，而且取下来麻烦（比赛中我们不打算取下来，一直带到终局）。

我们把它作为**保底方案**，如果储仓在 10-15 前调不稳就切这个。
（规则里没有禁止粘合剂；手册禁止的是"未干胶体等粘性液体"，双面胶不在此列。）

---

## 本板块参数

| 项目 | 值 |
|---|---|
| 储仓外廓 | 138 × 56 × 50 mm |
| 单格净内宽 | 42 mm（30mm 方块 + 12mm 余量 —— V1.4 方块变小后余量变大，不装隔板可当一个大兜用） |
| 底板倾角 | 前低后高 5° |
| 挡板 | 3 片，42 × 30 × 2mm，M2.5 铰接，背面加 1.5g 配重 |
| 单块质量 | 8.29 g（手册给出） |
| 3 块总重 | 24.9 g |

---

### 2026-10-10 · ★★★ 储仓换向 + 整体前移 + 取消斜底（本节 138×56×50 那套作废）

**为什么改**：机械臂改成"收起时朝正后方平躺"之后，以回转轴 `AB_AX = 106` 为圆心、
水平伸出 `18 + 105 = 123mm`，**爪子中心落在 `x = 106 − 123 = −17`**。
而旧储仓放在车尾 `x ∈ [−118, −18]`，爪的**两根手指**（`x ∈ [−36,−30]`、`[−4, 2]`）
正好**扎进储仓最后一列方块上方 8mm —— 撞了 2 格**（位置 (2,1) 和 (2,2)）。
这是用 `tools/check_arm_clearance.py` 数值复算抓出来的（最早靠看图纸判断成"不相交"，
因为只比了高度、忽略了爪的宽度）。

**三条修法一起做（缺一条都不行）**：

| | 改法 | 效果 |
|---|---|---|
| a | 储仓**整仓前移**到 `x ∈ [−32, +68]`（原 `BIN_X0 = −118`） | 爪停靠点 −17 落进仓内 |
| b | 中间 4 根立柱从 `x = ±4` 挪到 **`x = −45 / +78`** | 让出甲板中段（最大无支撑跨距 120mm，3N 下垂 ≈0.05mm，可忽略） |
| c | 储仓**最后一列中两排刻意留空**（`BIN_SKIP = ((0,1),(0,2))`） | 那两格就是爪的停车位兼投料口 |

复算结果 **0 干涉**。

**★ 尺寸与布局换了向，参数全部更新**：

| 项目 | 旧（作废） | **新（现行）** |
|---|---|---|
| 外廓 | 138 × 56 × 50（长×宽×高，车尾竖排 3 格） | **100（沿车长 x）× 136（沿车宽 y）× 52（高）** |
| 内部排列 | 3 格 × 1 排 | **3 列（列距 31，沿 x）× 4 排（沿 y）= 12 位** |
| 内腔 | 单格净内宽 42 | **94 × 130** |
| 装车位置 | 车尾 `x ∈ [−118, −18]` | **`x ∈ [−32, +68]`、`y ∈ [−68, +68]`（甲板中段）** |
| 有效容量 | 3 块 | **12 位，最后列中两排留空 → 实装 10 块**（随车 10 + 爪里还能夹 1） |
| 底板 | **前低后高 5°** | **平放**（★ 5° 斜底是无效设计：5° < PLA 之间约 19° 的摩擦角，方块根本滑不动） |
| 减震 | 无 | **垫 3mm EVA / 鼠标垫**（后两列投料落差 100~120mm，必须减震；顺带解决急停窜动） |
| 仓壁 | 56 宽侧板 | `13_bin_side`（100×52×3）×2 + `12_bin_floor`（100×136×3） |

**★ 换向后为什么容量反而大了**：旧方案是"沿车长竖着排 3 格"，格子少还占满车尾；
新方案把储仓**横过来**、沿车宽方向排 4 排，每排又沿车长排 3 列，
于是 12 位只占 100mm 车长。**换向是为了给平躺的机械臂让位** —— 这是被动改、但结果更好。

**★ 投料落差**：爪停靠点 `x = −17` 正在储仓最后一列（`x ∈ [−28.5, 1.5]`）正上方，
张口时方块从 z≈113 掉到仓底 91.5，**落差只有 22mm**，是全仓最温和的投料位。
另两列（x = 17.5 / 48.5）要靠摆角 48°/68° 才能对准，落差 100~120mm → 所以必须垫 EVA。

**★ 顶部单向挡板（`15_bin_flap`）与配重那两条仍然有效**（10-08 / 10-09 的结论不变）。

**★ 待复核**：`13_bin_side` 上隔板榫槽的位置随储仓换向后是否还能对上
（隔板 `14_bin_divider` 是 130×46×3）。

---

## 本板块参数（2026-10-10 现行值）

| 项目 | 值 |
|---|---|
| 储仓外廓 | **100（x 车长）× 136（y 车宽）× 52（高）mm** |
| 装车位置 | **x ∈ [−32, +68]、y ∈ [−68, +68]** |
| 内部排列 | 3 列（列距 31）× 4 排 = **12 位**，`BIN_SKIP = ((0,1),(0,2))` 留空 → **实装 10 块** |
| 内腔 | 94 × 130 mm |
| 底板 | **平放** + 垫 3mm EVA / 鼠标垫 |
| 壁厚 | 3 mm（`BIN_T`） |
| 挡板 | `15_bin_flap` ×2，背面加 M4 螺母配重（约 1.5g） |
| 单块质量 | 8.29 g（手册给出） |
| 10 块总重 | 82.9 g |

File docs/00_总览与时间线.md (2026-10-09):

# 工程日志 · 总览与当前进度

**队伍**：机器人总动员战队（重庆大学 · 新生组）
**仓库**：<https://github.com/peach-ai280/CRTC-Robot-Team>
**队伍英文名**：Robot Mobilization
**本文档更新**：2026-10-08
**中期提交截止**：2026-10-19 24:00

> 这是整个 `docs/` 的入口。先讲清我们做到哪一步、哪些是真跑通的、哪些还停在图纸上。
> **凡是没做出来的，我们都不写成做出来了。** 这是给自己立的规矩。

---

## 一、我们想做一台什么样的车

**两台车，走差异化分工**（不是两台一样的车）：

| | **1 号车（麦轮）** | **2 号车（橡胶轮）** |
|---|---|---|
| 轮子 | 麦克纳姆轮（全向） | 60mm 橡胶轮（**只能前后 + 转向**） |
| 擅长 | 平地、桥下 130mm 通道、一切需要精确对位的活 | **爬 26.57° 坡道、上 300mm 高台** |
| 主任务 | 地面 4 个白块 + **走桥进中央系统**（高台白块 + 焦点黄块）+ **洞穴 2 个黄块** ≈ **27 分** | 物资架 2 个黄块 + 高台白块 ≈ **16 分** |

> ★ **任务量是 27 : 16（约 63% : 37%），不是"一台扛全场"。**
> 1 号车的出发区 h5 本身就是 300mm 高台，走 f5/g5 两座桥可直达中央、**不用爬坡**；
> 这是它分值比 2 号车高的原因。完整重算见 `工程日志.md` 第九节。

**为什么要两台不一样**：没有任何一种轮子能同时"全向精确"和"能爬陡坡"。
麦轮在地胶上的摩擦系数只有约 0.5~0.7，而 26.6° 的坡**刚好需要 0.50** —— 几乎没有余量，一打滑就上不去；
橡胶轮摩擦够，但**不能横移**。所以让两台车各拿一头。

> ⚠ **这一条推翻了我们更早的判断。** 培训实测前，我们以为"爬坡收益是负的、干脆不爬"；
> 实车一试才发现，问题不在策略，而在**硬件选型**（官方 TT 马达 1:48 扭矩不够）。
> 完整推演见 `工程日志.md` 第五节。

- **半自动靠"机械对中"**（V 型口 + 微动开关），不靠视觉。
  理由写在了 `01`：对中的失败模式是"没对准"（无害，重来一次就行），
  视觉的失败模式是"对准了错的目标"（有害，扣时间还可能撞车）。
- **中期的时间安排**：到 10-19 只能做出 **1 号车**；2 号车的橡胶轮改装挪到中期之后。

---

## 二、这份日志怎么看

`docs/` 里**每个文件 = 机器人的一个功能板块**，正文写的是这个功能"要干什么"和"我们是怎么一步步做出来的"。

| 文件 | 讲什么 | 现在处在 |
|---|---|---|
| ★ **`工程日志.md`** | **主提交文档**：底盘运动 / 手柄遥控 / 桌面调试 / 物资采购 / **两车差异化配置** / **机械臂选型** / **两车任务量重算** / 开源说明 | **持续更新** |
| `00_总览与时间线.md` | 本文件，进度总表 | — |
| `01_规则拆解与战术选型.md` | 得分怎么算、走哪条路线（**"弃爬坡"一条已在 10-08 改口，见 `工程日志.md` 第五节**） | 方案定稿 |
| `02_机械结构与3D打印.md` | 尺寸红线核算、分层结构、打印件设计 | 模型完成，**未打印** |
| `03_底盘运动与麦轮防滑.md` | 麦轮解算、限幅、死区、斜坡、电压补偿 | 代码完成，**未实车跑** |
| `04_电源硬件与焊接.md` | 电源树、继电器、DRV8833 改造、5V 塌陷 | 方案定稿，**未接线** |
| `05_PS2手柄与遥控器.md` | SPI 协议、接线、掉线保护、按键 | **桌测进行中** |
| `06_舵机机构与抓取.md` | 夹爪、大臂、铲、挑杆、探杆 | 代码完成，**未装机构** |
| `07_方块携带与储仓.md` | 单向挡板、斜槽自锁、多块携带 | 设计完成，**未打印** |
| `08_半自动与视觉.md` | 对中检测、一键宏、K210（进阶） | 代码完成，**未实车调** |
| `09_结构稳定性成本与中期自查.md` | 跌落、尺寸、成本、考核自查、视频脚本 | 方案 + 待填表 |
| `调参指南.md` | 现场调参手册（实用工具，不是日志） | — |
| `硬件接线与焊接指南.md` | 引脚表、焊接点位、上电检查（实用工具） | — |
| `视觉模块选型与采购.md` | K210 选型对比（进阶备选） | — |
| `半自动与全自动操作手册.md` | 三档模式怎么切、宏怎么用 | — |
| `进阶功能方案.md` | 3 项进阶功能的设计与预算 | 设计完成 |
| `开源项目说明.md` | 我们用了哪些别人的东西、分别是什么许可 | **必读** |

---

## 三、我们做到哪一步了（截至 2026-10-08）

分成三档说，不混在一起。

### 3.1 已经跑通、有实测证据的

| 项 | 证据 |
|---|---|
| 电脑上的开发环境 | STM32CubeIDE 2.2.0 + arm-none-eabi-gcc 14.3.1 + 烧录器 STM32_Programmer_CLI + ST-LINK 驱动，**全部实跑通过** |
| 自己写的构建脚本 | `python tools/build.py ps2` 出固件：`text 19140 / data 468 / bss 3052` |
| **SWD 烧录链路** | `python tools/flash.py check` 实测返回：`Device ID 0x410`、`NVM 128 KBytes`、`Voltage 3.21V` |
| 仓库 | git 建好，首次提交 283 个文件已推到 GitHub，编译产物已用 `.gitignore` 排除 |

> `Voltage 3.21V` 这一行说明 ST-LINK 确实在给板子供电、芯片被正常识别 ——
> 整条"电脑 → ST-LINK → SWD → 芯片"的路是通的。**这是我们目前最实的一个进展。**

### 3.2 代码写完了，但还没上真车验证

固件是一个模块化的工程，下面这些都是**代码完成 + 离线仿真跑过**，但**没有在装了电机的真车上跑过**：

- 底盘全向运动（麦轮逆解 + 整体归一化限幅）
- 防滑四件套（加速度斜坡、死区补偿、起步助力、高速限自转）
- DRV8833 双路电机驱动（PHASE/ENABLE 接法）
- PS2 手柄 SPI 通信（含掉线保护）
- 舵机机构序列器、半自动一键宏、全自动调度器

> 我们另外写了一套 **C++ 版**放在 `cpp/`，能在**电脑上直接跑**（不用插板子）来验证参数。
> 一套 C 给比赛用，一套 C++ 用来学逻辑、离线验算，两套的参数必须同步改。

### 3.3 只有设计、还没动手的

- **3D 打印件**：模型和 STL 生成好了（25 个结构件 + 14 个外观件），**一件都还没打**。
- **整车装配**：没开始。车架、甲板、储仓、机械臂都还是模型。
- **机构实测**：夹爪开口、大臂高度、储仓能不能真装下 3 块方块 —— 都得等打印件到手才能验。
- **中期考核视频**：没拍。

---

## 四、物资分配（官方物资表 ¥353.48 是**两台车**的量）

| 谁拿 | 拿什么 |
|---|---|
| **算法组（电控 + 采购）** | STM32F103C8T6 ×2、ST-LINK ×1（全队共用）、PS2 手柄套装 ×2、DRV8833 ×4、降压模块 ×2、电池盒、充电器、面包板 ×2、杜邦线、无线继电器（**中期后**才买） |
| **建模组（结构）** | MG995 ×2、SG90 ×4、TT 马达 ×8、60mm 麦轮 ×2 套（**套装自带 TT 马达联轴器**）、4 轮金属底板 ×2 |
| 自备 | 18650 电池（**官方表里没有链接，注 5 明确要自行选型购买**）、电烙铁套装、热缩管、USB 转串口（CH340）、M3 螺丝螺母、扎带 |

> **目前实际到手的**：STM32 ×2、ST-LINK、PS2 手柄套装、面包板、三种杜邦线。
> 其余（麦轮、TT 马达、底板、电池）**还在采购中或由建模组保管** ——
> 所有依赖这些件的结论都标着「待实测」，没有拿设计值冒充实测值。

---

## 五、为什么我们先把力气花在电控上

三条理由，都是很实际的：

1. **电控是唯一不依赖别人的事。** STM32、ST-LINK、PS2 都在我们手上，插上电脑就能干；
   而机械那边要在 3D 打印件到手、车装起来之后才能往下走。所以先做电控，是把能提前的活提前做。
2. **电控是全队最容易卡住的一环。** 我们是新生，之前谁都没碰过单片机。
   手柄连不上、烧不进去、电机不转 —— 这些坑没人能替我们踩。
3. **底盘是所有动作的地基。** 不管后面做夹爪还是做全自动，车动不起来一切都是空的。

---

## 六、下一步（按"能不能马上做"排）

| 顺序 | 做什么 | 要等什么 |
|---|---|---|
| 1 | PS2 桌测：接 6 根线 → 烧 `flash.py ps2` → 板载灯常亮 | **不用等** |
| 2 | 焊 8 个马达焊点（**若换"免焊线版"TT 马达可跳过**） | 等烙铁到 / 换免焊款 |
| 3 | 马达拧上金属底板 | 等 M3 螺丝到 |
| 4 | 接电池 + DRV8833，**1 号车底盘跑起来** | 等电池/驱动到手 |
| 5 | **1 号车做完整**（含臂 / 储仓），并尽量让**2 号车裸底盘也能跑** | 等打印件、等队友结构件 |
| 6 | 拍中期视频、写提交邮件 | 前面都完成 |
| 7 | **中期之后**：2 号车换 1:120 马达 + 60mm 橡胶轮 | 中期结果出来 |

---

## 七、关于这份文档的三点说明

### 7.1 "设计值"和"实测值"我们分开放

`02`、`09` 里凡是尺寸、重量、耗时这类数字，**如果是从模型算出来的，就标"设计值"**；
**只有拿尺子/秤量过的才叫"实测"**。中期提交前我们会把"实测"那一列全部量一遍填上，
视频里也会拍到尺子读数。**不会把算出来的数当成量出来的交上去。**

### 7.2 遇到的坑，我们都留着了

写文档的时候我们把"哪里卡住了、怎么试出来的"都记下来了 —— 比如
PS2 调了三个小时最后发现是 DI/DO 接反、DRV8833 的 nSLEEP 悬空导致电机完全不转、
舵机一动单片机就复位。这些"翻车记录"我们没删，因为过程本身才是这份日志要看的东西。

### 7.3 用了多少别人的东西，全写在 `开源项目说明.md`

手册要求"引用了开源项目要在文档里完整说明"。我们**单独写了一篇**，逐条列清楚：
哪些代码是我们自己写的、参考了谁的公开资料、用的工具各是什么许可。
**这一篇请务必看。**

---

## 八、一句话总结

> **两台差异化底盘**：1 号车麦轮扫平地白块，2 号车橡胶轮爬坡抢高台和中央黄块；
> 半自动靠机械对中，不赌视觉、不赌全自动。
> **现在电控这一线的烧录链已经打通，代码写完待上真车；
> 机械还停在图纸上 —— 这段距离就是我们接下来要赶的路。**
> （中期只交 1 号车；2 号车的改装排在中期之后。）

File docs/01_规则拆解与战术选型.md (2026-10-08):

# 规则拆解与战术选型

> ⚠ **后续更新提示（2026-10-08，写在最前面以免误读）**
> 本文档下面的**战术推演是 9 月做的**，其中**"放弃爬坡"这一条已经被推翻**。
> 10-08 培训实车测试后查明：爬不上去的原因不是策略不对，而是**官方 TT 马达（1:48）扭矩不够**
> ——26.57° 的坡需要每轮约 0.34×车重(kg) 的扭矩，整车 1.09kg 时超出该马达能力约 30%。
> 于是我们改成**两台车差异化**：**1 号车留麦轮走平地，2 号车换 60mm 橡胶轮 + 1:120 马达专责爬坡**。
> **完整推演与规则依据见 `工程日志.md` 第五节**；本文档的其余部分（赛场几何、得分计算、
> 机械对中优先于视觉）**仍然有效**。

## 功能描述

把 22 页参赛手册翻译成"我们要做什么、不做什么、按什么顺序做"。
这一板块不产出代码，但它决定了后面所有设计的前提 —— 新手队最容易犯的错就是
跳过这步直接画车，画到一半发现尺寸超标、得分路径根本走不通。

---

### 2026-09-15 · 组队完成，第一次通读手册

5 人组队完成，全部为重庆大学 2026 级本科生，符合新生组资格（手册 2.2：新生组所有队员必须为 2026 级本科）。
队名按「<队伍名称> + 战队」格式定为**机器人总动员战队**（6 个汉字 = 12 字符，符合 ≤12 字符要求）。

第一次通读后的三条共识：

1. **这是资源争夺赛，不是擂台赛。** 胜负看的是"比赛结束时你车上还剩几个道具"，
   不是"把对方撞死"。所以**收集和保有**是主矛盾，机动性是次要矛盾。
2. **道具数量是有限的**：能量单元 18 个 + 能量核心 5 个 = 23 个，**场上道具被全部收集完毕时当局直接结束**。
   这意味着"抢得慢"不只是少拿分，而是会提前结束比赛、连对手的机会也一起砍掉 —— 反过来，
   如果我们抢得快，对手的时间也会被压缩。这是本规则里最容易被忽略的一条杠杆。
3. **5 分钟一局**，2 台车，2 名操作手。人均操作压力大，动作越自动化越占便宜。

### 2026-09-16 · 得分规则量化：算清楚"够用分"

手册 4.1 / 5.4 的得分表：

| 道具 | 数量 | 基础分 | 半自动倍率 | 全自动倍率 |
|---|---|---|---|---|
| 能量单元（白色 30mm 立方体） | 18 | 1 分 | ×1.5 → 1.5 | ×2 → 2 |
| 能量核心（黄色 30mm 立方体） | 5 | 4 分 | ×1.25 → 5 | ×1.5 → 6 |

理论满分 = 18×2 + 5×6 = 66（全全自动且全收集完）。

**现实估算**（我们对自己能力的判断）：

| 方案 | 拿到什么 | 得分 |
|---|---|---|
| 保守：只捡地面白块 | 8 个白块，半自动 | 8 × 1.5 = **12** |
| 中等：白块 + 焦点黄块 | 10 白 + 1 黄 | 10×1.5 + 1×5 = **20** |
| 激进：白块 + 3 个黄块 | 12 白 + 3 黄 | 12×1.5 + 3×5 = **33** |

**结论：黄块收益极高（一个顶 3.3 个白块），必须优先。**
5 个黄块的位置：
- 2 个挂在 e3 / d6 台阶的物资架上（质心距地 250mm）
- 2 个在 d1 / e8 台阶下的洞窟里（70×70×50 向外开口）
- 1 个在中央高台的焦点平台上

但黄块**获取难度大得多**：要爬 150mm 台阶 / 伸手进洞 / 上 300mm 高台。
我们的判断是：**焦点那 1 个黄块性价比最高**，因为 1 号机从高台启动区出发，
走桥就能到中央高台，**全程不用爬坡**。

### 2026-09-17 · 定核心战术：1 号机走桥

这一天的收获是整份文档里最有价值的一条。

手册 4.2 的场地要素里有个容易看漏的组合关系：

```
启动区：a1(红2号)  a4(蓝1号)  h5(红1号)  h8(蓝2号)
高台(300mm)：a4, d4, d5, e4, e5, h5
坡道(300mm高,坡比0.5)：a5+a6(连 a4 高台), h3+h4(连 h5 高台)
桥梁：b4, c4 相连 → 连接 a4 高台 与 d4 高台
      f5, g5 相连 → 连接 e5 高台 与 h5 高台
```

**关键推论**：红方 1 号机的启动区 **h5 本身就是一个 300mm 高台**。
而 h5 通过 f5、g5 两座桥直接连到 e5，e5 属于中央高台（d4/d5/e4/e5）。
也就是：

> **1 号机不需要爬任何坡，走一段桥就能站到中央高台上，直接够到焦点黄块。**

对比之下，2 号机在地面（a1 / h8），要上中央高台只能爬 26.6° 的坡道（坡比 0.5 → arctan(0.5) ≈ 26.57°），
而麦轮是塑料辊子、在白色地胶上的摩擦系数我们估 0.5~0.6，**刚好在打滑边缘**。

于是战术定为：

| 机器人 | 起点 | 任务 | 为什么 |
|---|---|---|---|
| **1 号机**（桥行者） | 高台 h5 | 过桥 → 中央高台 → 抢焦点黄块 + 中央的 4 个能量单元 | 不用爬坡，路径最短，黄块分值最高 |
| **2 号机**（拾荒者） | 地面 a1 | 扫地面能量单元；顺路够 e3/d6 物资架、d1 洞窟 | 数量多、风险低、不依赖爬坡 |

**明确放弃的**：让 2 号机爬坡上中央高台。理由是我们没有编码器，
开环爬 26.6° 坡一旦打滑就会溜车，溜下来可能连已收集的白块一起甩掉 —— 期望收益为负。

> ⚠️ 手册里**没有**"所有组别必须完成半自动"这一条（我们逐条核对过 4.1 的基础功能清单）。
> 半自动/全自动只是**得分倍率**（×1.5 / ×1.25）。
> 我们仍然要做半自动，因为 1.5 倍是白给的，但不是因为"不做就违规"。

### 2026-09-18 · 物资到货清点与成本基线

官方物资表总额 **¥353.48**（不含无线继电器 ¥27.6，因为规则说未通过中期考核的队不用买）。

清点结果（两套车平分）：

| 物资 | 数量 | 每车分配 |
|---|---|---|
| STM32F103C8T6 核心板（焊接款） | 2 | 1 |
| MG995 舵机 180° | 2 | 1 |
| SG90 舵机 180° | 4 | 2 |
| PS2 无线手柄（锁频款 + 转接板） | 2 | 1 |
| TT 马达 1:48 | 8 | 4 |
| 60mm 麦克纳姆轮（含联轴器） | 2 套 | 1 套 |
| 4 轮金属底盘折弯板 | 2 | 1 |
| ST-LINK V2 | 1 | 共用 |
| DRV8833 驱动模块 | 4 | 2 |
| Mini 降压模块 5V | 2 | 1 |
| 18650 电池 / 两节电池盒 / 充电器 | — | 1 套 |
| 面包板 / 杜邦线 | — | 共用 |

**第一次成本决策**：MG995 只有 2 个、SG90 只有 4 个，每车只能分到 **1 个 MG995 + 2 个 SG90 = 3 个舵机**。
而"舵机运动（多项）"考核指标要求**同一台机器人至少 3 个舵机**转动。
所以——**3 个舵机的分配不是够用，而是刚好卡在及格线上，一个都不能浪费。**

最终分配（两台车完全一致，便于互换备件）：

| 舵机 | 用途 |
|---|---|
| MG995（大扭矩） | 大臂抬升（唯一需要出力的关节） |
| SG90 #1 | 夹爪开合 |
| SG90 #2 | 前铲 / 翻板 |
| SG90 #3（第 4 个 SG90 拆给备用件） | 备用挑杆 / 探杆 |

### 2026-09-11 ·（补记）为什么不赌全自动

手册对全自动的定义是"**无需配备操作手，且经组委会审查确定为自动运行**"。
注意"经组委会审查确定"这半句 —— 认定权在组委会，不在我们。

我们的判断：

1. 没有编码器、没有 IMU、没有视觉的话，开环盲走的"全自动"本质是定时器，
   撞一次就全盘崩溃，而场地是 2400×2400 的对抗场，撞是必然的。
2. 一旦被认定成全自动但表现拉胯，反而失去了操作手的纠错能力。
3. 全自动的倍率优势（×2 vs ×1.5）只有 33%，**不值得赌上稳定性**。

所以定下：**做半自动，让操作手按一个键触发一个有超时上限、可被打断的动作序列**。
决策权始终在人手里，认定上最稳妥。

---

## 本板块的遗留问题

- 【待回填】e3 / d6 物资架上黄块的**实际**挂法（是穿在 14mm 圆柱上还是挂在末端），
  需要现场确认，直接决定挑杆是"从下挑"还是"从侧拨"。
- 【待回填】中央高台 d4/d5/e4/e5 之间的接缝是否平整，不平的话 1 号机过桥后会颠。

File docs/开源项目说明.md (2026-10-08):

# 开源项目与外部资源说明

比赛手册要求：**如果引用了开源项目，必须在文档里完整说明。** 这一篇就是干这个的。

我们从零搭这套东西，能自己写的都自己写了。但"自己写"不等于"凭空想出来" ——
协议怎么定、引脚怎么排、许可怎么算，都得查公开资料。所以下面分几块讲清楚：

1. **哪些是我们自己写的**
2. **参考了哪些公开资料**（看了才知道，但没搬代码）
3. **机械臂候选开源方案**（已评估，**尚未采用**）
4. **直接用了哪些开源软件**（真的装在电脑上跑的）
5. **开发工具链**

---

## 一、我们自己写的东西

| 东西 | 位置 | 说明 |
|---|---|---|
| **整套固件** | `firmware/Core/` | 底盘运动学、麦轮解算、电机驱动、PS2 通信、舵机机构、半自动宏、全自动调度 —— 全部自己写 |
| **HAL 兼容层** | `firmware/Core/Src/hal_shim.c` + `Inc/stm32f103_regs.h` | 见下方专门说明 ⬇ |
| **启动文件** | `firmware/Core/Src/startup_stm32f103xb.c` | 官方是汇编 `.s`，我们**用 C 重写**，把"搬 .data / 清 .bss / 跳 main"三件事写成看得懂的代码 |
| **链接脚本** | `firmware/STM32F103C8TX_FLASH.ld` | 按我们这块芯片的 Flash/RAM 大小写的 |
| **C++ 学习与验证版** | `cpp/` | 同一套算法的 C++ 实现 + 一个能**在电脑上直接跑**的模拟器 |
| **参数化建模脚本** | `mechanical/gen_parts.py`、`gen_shell.py`、`gen_gauge.py` | 改尺寸就重跑，不用手工在 CAD 里画 |
| **切片与打印工具** | `tools/slice_k1.py`、`check_gcode.py`、`print_bill.py` | 我们自己写的切片器（本机没装切片软件），出 K1 Max 能直接打的 G-code |
| **构建与烧录脚本** | `tools/build.py`、`flash.py`、`check_symbols.py` | 代替 make 和 CubeIDE 图形界面，一条命令出固件 / 烧进去 |
| **装配示意图生成** | `tools/render_asm.py`、`render_wheel_note.py` | 用真实 STL 数据离线出图 |
| **视觉脚本** | `vision/k210_find_cube.py` | 跑在 K210 上找色块，通过串口把坐标发给 STM32 |

### 关于 `hal_shim` —— 这一段必须说清楚

原本的标准做法是用 ST 官方的 **HAL 库 + CMSIS 头文件**。但我们这套环境里拿不到官方库，
于是我们**自己写了一个兼容层**：用直接操作寄存器的方式，实现了业务代码里用到的
20 来个 HAL 函数（`HAL_GPIO_WritePin`、`HAL_TIM_PWM_Start`、`HAL_SPI_TransmitReceive` 等）。

- **函数名和参数与 ST 官方 HAL 保持一致** —— 这样业务代码一个字不用改，
  而且将来如果拿到官方库，把 `main.h` 里的一行 `#include` 换掉就能切回去。
- **函数体是我们自己写的寄存器操作**，没有拷贝 ST 的任何源码。
- 寄存器地址定义在 `stm32f103_regs.h` 里，是我们按芯片参考手册（RM0008）里的地址表写的。

> 为什么敢这么干：我们用到的 HAL 函数只有 20 来个，全是"配置一次性外设"的性质，
> 不涉及 DMA、中断优先级分组这些复杂状态机，逐个核对是可行的。

---

## 二、参考过的公开资料（看了才知道，没有搬代码）

| 资料 | 用来搞清什么 | 说明 |
|---|---|---|
| **STM32F103C8T6 最小系统板（俗称"蓝色药丸"）引脚定义** | 板子左右两排 40 个针分别是什么、`PA13/PA14` 在哪儿 | 板子不带引脚图。我们查了 stm32-base 项目的 F103 引脚表、多篇公开讨论，**交叉核对后才动手接线**。属公开硬件知识。 |
| **ST-LINK V2 兼容版 10 针接口的排布** | 10 个针里哪 4 个是我们要用的 | 参考了 `github.com/noahp/stlink-clone-adapter` 对克隆版的整理：**2016 批次和 2020 批次排布不一样，外壳丝印可能是错的**。这条直接改变了我们的接法（只认印的字，不认针号）。 |
| **PS2 手柄串行通信协议** | 一帧怎么发、9 个回应字节各代表什么、初始化要发哪几条命令 | 这是公开协议。Arduino 平台有知名的 PS2X 库等实现描述了它。**我们只照协议描述自己写了 SPI 收发和初始化序列，没有引用任何库代码。** |
| **Klipper / Marlin 的 G-code 指令集** | 给 K1 Max 出什么格式的 G-code | 两者都是成熟的开源 3D 打印机固件，我们按其通用指令规范输出（只用标准命令，不碰厂商专有宏）。 |

---

## 三、机械臂候选开源方案（已评估，**尚未采用**）

我们在给机械臂做选型调研时，看过几个 GitHub 上的公开项目。
**截至本文更新，我们还没有直接采用其中任何一个的模型文件或代码** ——
只参考了公开的连杆原理和标定思路，**尺寸全部自己出**
（原因：我们的车长只剩 7mm 余量，现成模型的尺寸对不上，硬搬会直接让整车超尺寸）。

| 项目 | 许可 | 形态 | 我们参考了什么 |
|---|---|---|---|
| **MeArm** | MIT | 4 自由度舵机臂，臂展约 200mm，底板固定式 | 连杆几何、舵机姿态角的标定方法 |
| **EEZYbotARM MK2** | CC BY-NC-SA 4.0 | 3D 打印件 + 舵机，件数较多 | 平行四边形结构"保持末端姿态恒定"的思路 |
| 通用"舵机码盘 + 平板连杆"公开教程 | 无特定许可 | 无固定尺寸 | 舵机关节的通用做法经验 |

> ⚠ **登记义务（写在这里提醒自己）**：如果后续真的**直接采用了上面任一项的模型文件或代码**
> （而不是"只看了原理"），必须回到这张表补上四件事：**项目名 + 作者 + 链接 + 许可**，
> 并说明我们改了什么。这是手册的硬要求（"使用开源项目……应当在文档末尾完整说明"）。
> **当前状态：只参考原理，没有搬运任何文件，因此目前不构成"使用开源项目"。**

---

## 四、直接安装并使用的开源软件

这些是**真的装在电脑上、跑起来用的**，和上面"参考资料"是两回事。

| 名称 | 用在哪儿 | 许可 |
|---|---|---|
| **numpy** | 所有建模 / 切片 / 出图脚本的数值计算 | BSD-3-Clause |
| **shapely** | 切片时求轮廓交并、建模脚本的布尔运算 | BSD-3-Clause |
| **numpy-stl** | 读写 STL 网格文件 | BSD-3-Clause |
| **Pillow (PIL)** | 生成装配示意图的位图 | MIT-CMU (HPND) |
| **unicorn** | **离线仿真**：在电脑上模拟一颗 ARM Cortex-M3，直接跑我们编译出来的真实固件机器码，看电机/舵机输出对不对 | GPLv2 |
| **gmsh** | 需要时校验导出的 STEP 文件体积（选装） | GPLv2+ |

> ⚠ **重要边界**：上面这些库**只在开发和验证阶段用**，**不参与比赛现场运行的固件**。
> 车上跑的固件只依赖 C 标准库和芯片本身。

---

## 五、开发工具链

| 工具 | 干什么 | 性质 / 许可 |
|---|---|---|
| **STM32CubeIDE 2.2.0** | 提供 ARM 编译器、烧录器和 ST-LINK 驱动 | ST 官方**免费**软件（非开源） |
| **arm-none-eabi-gcc 14.3.1** | ARM 交叉编译（把 C 编成芯片能跑的机器码） | GPLv3 + GCC Runtime Library Exception |
| **STM32_Programmer_CLI** | 通过 ST-LINK 把固件写进芯片 | ST 官方免费软件 |
| **Python 3.13** | 跑上面所有辅助脚本 | PSF License |
| **Git for Windows** | 版本管理、把代码推到本仓库 | GPLv2 |

---

## 六、一句话交代

> **代码是我们自己写的，协议和引脚是查公开资料搞清楚的，电脑上跑的工具都有各自的开放许可。**
> 唯一"和别人一样"的地方是 `hal_shim` 里的函数名 —— 那是故意跟 ST 官方 HAL 保持一致的，
> 为了将来能一键切回官方库，**实现是我们自己写的寄存器代码**。
>
> 我们是一支全员新生的队伍，很多东西是边查边试出来的。文档里保留了大量试错过程
> （比如 PS2 查了三小时最后发现是两根线接反），因为这些才是这份日志该有的样子。

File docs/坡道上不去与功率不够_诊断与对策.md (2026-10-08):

# 坡道上不去 / 功率不够 / 马达承不住 —— 诊断与对策

> CRTC2026 机器人总动员战队 · 电控与采购
> 依据：参赛手册 V1.5（第 16 页场地 / 第 22–23 页官方物资表）
> 2026-10-08
> ⚠ **更新（同日深夜）**：本文是最初的**诊断记录**。后续已产出**两级分档定稿方案**
> （见同目录《改进方案_定稿_爬坡与动力.md》）——**第一级不动结构、不改运动学、保住横移**
> （换 1:120 马达 + O 型圈 + 高倍率电池 + 硅胶线 + 电容），**第二级才换橡胶轮**。
> **采购优先级以定稿为准**，本文第九节"先买橡胶轮"的排法已被取代。
> 另外**两车差异化配置**（1 号车留麦轮、2 号车换橡胶轮）见《两车差异化配置_可行性与中期考核口径.md》。

---

## 零、一句话结论

**这不是"调调参数"能解决的事，是硬件选型本身不够——官方那套 TT 马达 + 麦轮的组合，在 26.6° 的坡面上只有约三分之一的余量，整车一超过 0.6kg 就上不去。**

而且**加大功率的方向不是加电压**（TT 马达额定只有 3~6V，我们已经在用 7.4V，已经超压 40%），
正确方向是**加扭矩（换减速比）+ 减少损耗（电池、线、接触电阻）**。

---

## 一、先把数字摆出来（这些是手册写死的，不是感觉）

### 1. 坡道到底多陡

手册第 16 页原文：

> 坡道为占据 1×2 单位区块，连接地面与高台的地形区。坡道的坡高为 **300mm**，**坡比为 0.5**。

- 1×2 单位区块 = **300mm × 600mm**
- 坡比 0.5 = 高 300 ÷ 水平 600
- **角度 = arctan(0.5) = 26.57°**（约 26.6°）

台阶坡道（e1、d8）：坡高 **150mm**、坡比同为 0.5 → **角度一样是 26.6°**，只是坡面短一半（水平 300mm）。

> ⚠ **"角度有点大"是正常的，手册就是这么定的。** 但值得量一下——现场坡道可能是临时搭的。
> 量法：量坡道从底到顶的**水平距离**。300mm 高对应 600mm 水平。如果实测水平只有 400mm，那现场搭成了 36.9°，属于搭错，可以反馈组委会。

### 2. 我们的电机是什么货色

官方物资表第 5 项：**TT 马达 单轴 1:48**，单价 ¥2.83。

公开数据（多个来源一致）：

| 项目 | 数值 |
|---|---|
| **额定电压** | **3 ~ 6V**（不是 7.4V！） |
| 空载转速 | 200~250 rpm @6V |
| **堵转扭矩** | **0.8 kg·cm @6V** |
| **堵转电流** | **1.5A @6V**（8.4V 时约 2.1A） |
| 齿轮箱 | **塑料齿轮** |
| 重量 | 30.6g |

关键：**它是 3~6V 的马达。**
手册规定"单一供电、额定 ≤7.4V"——我们上 2S 锂电（标称 7.4V / 满电 8.4V），**等于让一个 6V 的马达常年跑在 8.4V**。
有刷电机超压不会立刻烧，但**电流和发热按比例上升，塑料齿轮箱的寿命直接砍半**。这就是"马达承不住"的第一个来源。

### 3. 驱动是什么货色

官方物资表第 9 项：**DRV8833 红板**，4 个（两台车 → **一台车 2 个 = 4 个通道 = 正好一个电机一个通道**）。

| 项目 | 数值 |
|---|---|
| 持续电流 | 1.2A / 通道 |
| 峰值电流 | 2A / 通道 |
| 内部压降 | 约 0.6~1.2V |

**一台车 4 个电机，每个电机堵转就要 2.1A，而 DRV8833 单通道峰值只有 2A。**
→ 一上坡、电流一冲，驱动模块就进限流/过热保护，表现就是**"一冲一冲"、"软绵绵"、"越爬越没劲"**。

### 4. 车重决定一切

上坡需要的**每轮扭矩**，可以套一个很简单的公式：

```
每轮需要扭矩 (kg·cm) ≈ 0.34 × 车重 (kg)
```

| 车重 | 每轮需要 | 4 轮合计需要 | TT 1:48 能持续给 | 结论 |
|---|---|---|---|---|
| 0.5 kg | 0.17 | 0.68 | 4 × 0.28 = 1.12 | ✅ 能上 |
| 0.6 kg | 0.20 | 0.82 | 1.12 | ✅ 勉强能上 |
| 0.8 kg | 0.27 | 1.09 | 1.12 | ⚠️ 贴边，一打滑就上不去 |
| **1.09 kg（我们整车的设计重量）** | **0.37** | **1.46** | 1.12 | ❌ **差 30%，上不去** |
| 1.5 kg | 0.51 | 2.04 | 1.12 | ❌ 差 45% |

（TT 1:48 的"持续可用扭矩"按堵转的 1/4 取，即 0.8 ÷ 4 = 0.2 kg·cm @6V，8.4V 时约 0.28 kg·cm。这是工程上的常规取值，留够发热和寿命的余量。）

**结论：整车一旦超过 0.6kg，1:48 的 TT 马达就爬不动 26.6° 的坡。**
我们的车设计重量 1.09kg——**超了将近一倍**。这不是调参数能救的。

---

## 二、为什么"麦轮"让这件事雪上加霜

麦轮的爬坡能力差，是行业公认的结构性缺陷（连专利文献都在专门研究怎么给麦轮加爬坡防滑装置）。原因：

1. **接触是点接触 / 线接触**。每个轮子是靠一圈 45° 斜装的小辊子接地的，接地面积远小于普通轮胎，压强高、抓地力低。
2. **没有纯纵向牵引力**。麦轮的正向力会被斜辊子分解，一部分变成辊子自转白转掉。业界共识是"无法提供纯纵向牵引力，因此爬坡和越障能力较弱"。
3. **接触点小 → 一颠就悬空**。坡面上只要有一个辊子过了坡道棱边，那个轮子就瞬间失去附着。
4. **地胶表面 + 麦轮橡胶辊子，摩擦系数大概就是 0.5~0.7。**

**第 4 点最要命：**

```
要能上 26.6° 的坡，摩擦系数必须 ≥ tan(26.6°) = 0.50
麦轮在 PVC 地胶上的实际摩擦系数 ≈ 0.5 ~ 0.7
```

→ **余量几乎为零。** 地胶上有一点灰、一点水汽、辊子上有一点磨光，摩擦系数掉到 0.5 以下，**轮子就纯打滑，扭矩再大也没用**。

普通橡胶轮在地胶上的摩擦系数约 0.8~1.0，**余量 60% 以上**。

---

## 三、先花 3 分钟判断：到底卡在哪一环

**别急着买东西。先分清是"打滑"还是"没劲"——这两个的解法完全相反。**

| 你看到的现象 | 判断 | 病根 | 看第五节哪一档 |
|---|---|---|---|
| 轮子**转得飞快**、嗡嗡响、车几乎不往前走 | **打滑** | 摩擦不够（麦轮 / 地胶 / 车太轻压不住） | 第 3 档 A |
| 轮子**转得很慢甚至不转**、电机或驱动板**发烫** | **没劲** | 扭矩不够 / 过流保护 | 第 3 档 B、C |
| **一冲一冲**、走两步停一下 | **过流保护跳了** | DRV8833 单通道顶不住 | 第 2 档 D |
| 某个轮子**完全不转**或**咔咔响** | **齿轮扫了 / 线断了** | 塑料齿轮崩齿 | 第 3 档 D |
| 爬一半**车头翘起来**、后轮空转 | **重心太靠后** | 配重问题 | 第 1 档 C |
| 平地就好好的，**一上坡就瘫** | **电池撑不住** | 内阻大、瞬时掉压 | 第 2 档 A |

**再补两个 0 成本的量法：**

- **量电池**：万用表搭电池正负极。满电应是 **8.4V**。挂上坡时如果掉到 **6.5V 以下**，就是电池内阻太大 → 见第 2 档 A。
- **量坡度**：手机装个"水平仪"/"量角器"App，贴在坡面上读角度。26.6° 是规范值。实测超过 30° 就找组委会问。

---

## 四、★ 还有一个免费的大检查：麦轮装反了没

**这一条能单独解释"没劲"和"乱跑"。**

麦轮分 **A 型（辊子左旋）** 和 **B 型（辊子右旋）**。标准 X 型四轮布局要求：

```
        车头
  左前(B)      右前(A)
  左后(A)      右后(B)
        车尾
```

**检查方法（不用拆）：**
把车架空，四个轮子往前转，从上往下看，**左侧两个轮的辊子接触地面那一点，应该同时朝车头方向；右侧两个轮同时朝车尾方向**（或整体镜像反过来）。四个轮连起来在地面画出来是一个 "X"。

**如果装错了**：四个轮子互相打对台，电机在使劲但力全互相抵消——平地就慢，一上坡直接瘫。而且耗电、发热都翻倍。

> 我们配件是"麦轮一套 4 个"，**开箱时左右是配好的**，装的时候别把顺序打乱。左前左后不是同一型。

---

## 五、怎么办 —— 按代价从低到高，五档

### 第 1 档：免费，今天就做

**A. 助跑冲坡。**
坡道是 1×2 区块，底端外面还有平地。**从 600mm 开外全速冲上去**，用动能顶着过最陡的一段。这是最有效的一招，因为 5 分钟内比赛，你只要上一次坡就够了。

**B. 正对上坡，别斜着上。**
麦轮斜着上坡会沿辊子方向侧滑，等于自己给自己打滑。**车头正对坡道中线，垂直上。**

**C. 减重 + 重心压低靠中。**
- 试底盘阶段就**别装储仓、机械臂、甲板**——那些加起来 500g 以上。
- 电池**尽量放低、放在车体中间**。上坡时重心后移，重心太靠后会抬起前轮，只剩两个轮子驱动。
- 装完第一件事：**上秤**。

**D. 比赛用满电的电池。**
8.4V 满电比 6.8V 亏电，扭矩高 **23%**。这不是小数。**带两块备用电池，每局换一块满电的。**

**E. 先从"矮坡"练。**
e1 / d8 的坡道是 **150mm 高、坡面水平 300mm**。角度一样是 26.6°，但**爬升高度只有一半，需要的能量只有一半**。先用这两条练，成功率高得多。

### 第 2 档：几十块钱的电气改造（性价比最高）

**A. ★ 换高倍率动力 18650。**
这大概率就是"整体功率不够"的主因。
- 4 个电机堵转一瞬间要 **6~8A**。普通 18650（容量型，2C 放电）内阻大，电流一冲电压就塌。
- 换**持续放电 10A 以上**的动力电芯：索尼 VTC6 / 三星 25R / 30Q，或国产标注 10C 以上的。约 **¥15~25/节 × 2 节**。
- ⚠ 仍然是 2 节、仍然是 7.4V，**不违规**。

**B. ★ 电机供电走粗线，绕开面包板。**
面包板每个簧片接触电阻 20~100mΩ，杜邦线 28AWG 也细。**2A 电流下，光这些接触点就能吃掉 0.5V 以上**。
- **电机回路（电池 → DRV8833 → 电机）单独用 20~22AWG 硅胶软线，直接对接，不走面包板。**
- 面包板只留给信号线（PS2、舵机 PWM、使能）。

**C. 每个 DRV8833 模块旁边并一个电解电容。**
470µF ~ 1000µF，耐压 16V 以上。**紧贴模块的 VM 和 GND 焊**。
作用：堵转的瞬间电流从电容里出，不从电池里出，避免电池被瞬时拉垮。
⚠ 电解电容**有正负极**，长脚是正，别接反（接反会炸）。

**D. 确认"一个电机一个通道"。**
官方一台车给 2 个 DRV8833 = 4 个通道 = 4 个电机**正好一拖一**。别为了省事拿一个通道带两个电机，那一定没劲。

**E. 检查 DRV8833 的 nSLEEP 引脚。**
有些模块的 nSLEEP 悬空时输出很弱或不出力。**接 VCC**（模块上一般已经拉了，但确认一下）。

### 第 3 档：机械改动（最有效，要花点钱动手）

**A. 给麦轮辊子加防滑（¥5~20，成本最低的机械改动）**
- 每个辊子上套一圈 **O 型橡胶圈**，或缠几层**热缩管**，或把硅胶条塞进辊子之间。
- 目的：把辊子与地胶的摩擦系数从 0.5 拉到 0.8 以上。
- 代价：横移会稍微变钝一点点，但换来的是能爬坡。

**B. ★★ 换成 60mm 橡胶轮（最有效，且完全合规）**
- **合规性**：手册附录注 2 原文——"**对于新生组而言，CRTC 官方物资表作为官方推荐的物资清单**，参赛队员可考虑购买其他不在 CRTC 官方物资表内的物资参加比赛，但购买的物资仍需符合赛事规则。"
  **注 3 的"唯一指定物资清单"只约束非新生组。我们是新生队，可以买表外物资。**
- 规则对"底盘运动"的判定只写"能用 PS2 手柄控制底盘的**水平运动**"，**没有强制麦轮、没有强制全向、没有强制爬坡能力**。
- **效果**：摩擦系数从 0.5 → 0.9，等于牵引力接近翻倍。26.6° 立刻从"上不去"变成"轻松上"。
- **代价**：失去横移（全向）。**但横移对拿分不是必须的**——贴边、对位用差速转弯都能做。
- 买法：搜"**60mm 橡胶轮 TT 马达 通用 D 轴**"，¥10~20 / 4 个。
- ⚠ 必须买 **D 轴 5.5mm 孔**（TT 马达输出轴就是 D 轴）。

**C. ★★ 换 1:120 减速比的 TT 马达（真正解决"扭矩不够"）**
- 同一款马达，齿轮比从 1:48 换成 **1:120**：
  - **扭矩 × 2.5** → 持续可用约 0.5 kg·cm @6V、0.7 kg·cm @8.4V
  - 4 轮合计 2.8 kg·cm，**需求才 1.46** → **余量接近 2 倍，稳上**
  - 速度 ÷ 2.5 → 从约 0.88 m/s 降到约 **0.35 m/s**
- **代价：慢。** 全场 2.4m 跑一趟要 7 秒。5 分钟的比赛还够用，但**抢块会比对手慢**。
- 买法：搜"**TT 马达 1:120 单轴**"，¥3~4/个 × 8 个 = **约 ¥30**。
- ⚠ 一定买**单轴**版（双轴装不进原来的联轴器）。
- ⚠ 换完**必须重新标定速度宏**，见第六节。

**D. 换 1:90 金属齿轮 TT 马达**
- 扭矩 ×1.9、**金属齿轮不扫齿**，速度降到约 0.45 m/s。
- 是"速度"和"爬坡"之间的折中点，但**扭矩余量只有 30%，还是贴边**。不如直接上 1:120。
- ¥6~8/个。

**E. 换 N20 / 370 减速电机（激进方案）**
- N20 金属齿轮 1:150 左右，扭矩 1~3 kg·cm，那才是真的"有劲"。
- **但**：安装座要 3D 打印、联轴器要重做、底板孔位要改 → **要队友配合，工作量大**。
- 建议**先不动**，等第 3 档 B+C 试完再说。

### 第 4 档：如果连 B+C 都不想动

**A. 用"麦轮 + 橡胶爬坡套"两套轮子。**
平时用麦轮（要横移），要上坡前 10 秒把橡胶轮换上（TT 马达拆装轮子只要拧一个螺丝）。
**这是最省事的组合拳**：¥15 买一套橡胶轮当备用，比赛看路线决定用哪套。

**B. 只走地形简单的那半场。** 见第七节。

---

## 六、换完减速比后，代码要改哪些

换 1:120 后，**轮子转得慢了 2.5 倍**，但麦轮逆解的几何参数（WHEELBASE / TRACK / 轮半径）**不用改**——那是几何，不是转速。

要改的是**速度标定**这三个宏（`firmware/Core/Inc/config.h`）：

```c
#define SPEED_GAIN_FORWARD       0.85f   /* 平地巡航，可以保持 */
#define SPEED_GAIN_STRAFE        0.85f   /* 必须和 FORWARD 相等，否则斜着走会偏 */
#define CHASSIS_ACC_UP           3.0f    /* 起步斜坡 */
```

**做法（顺序别乱）：**

1. **先跑平地标定**：编 `motion` 目标烧进去，手柄推到底直走 1m，量时间，算出实际速度。
   - 1:48 理论 0.88 m/s → 1:120 应该在 **0.35 m/s** 左右。偏离太多说明有轮子装错或打滑。
2. **`SPEED_GAIN_FORWARD` 和 `SPEED_GAIN_STRAFE` 必须始终相等**。
   不等的话，斜向走会偏——1:48 的情况下，0.85 对 0.80 就会偏 1.74°。这是我们已经踩过的坑。
3. **`CHASSIS_ACC_UP` 从 3.0 提到 5.0~6.0**：1:120 起步更"沉"，斜坡太缓会显得肉。
4. **起步 kick 可以调大一点**：`MOTOR_KICK_DUTY` 从 0.12 提到 0.18，帮它从静止捏过静摩擦。
5. 改完按自检流程跑一遍：`python tools\build.py all` → `python tools\check_symbols.py`。

**（可选，进阶）加一个"爬坡档"：**
在手柄上留一个按键，按下去时把 `SPEED_GAIN_FORWARD` 临时提到 1.0、`CHASSIS_ACC_UP` 提到 8.0。
平地用 0.6 保护电机，上坡时一键给满。这样既保护马达又能爬坡。

---

## 七、★ 战术绕行：其实不一定非得上坡

**这是 0 成本、且最应该先算清楚的一件事。**

### 场地上的道具分布（手册第 17–18 页）

**白色能量单元（1 分，共 18 个）：**

| 位置 | 要不要上地形 |
|---|---|
| a8、h1 地块中心 | ❌ **地面，直接拿** |
| c4、f5 地块中心 | ❌ **桥下地面**（桥梁净高 130mm，下方有通行空间，车能钻进去） |
| d6、e3 台阶内侧四分之一处各 1 个 | ⚠️ 要上 150mm 台阶 |
| e8、d1 台阶几何中心 | ⚠️ 要上 150mm 台阶 |
| e8'、d1' 附属高台矮墙中心 | ⚠️ 要上 20mm 附属高台（好上） |
| 地图中心轴距中心 40mm 处四个（矮墙限位） | ❌ 在中央高地上，要上 300mm |

**黄色能量核心（4 分，共 5 个）：**

| 位置 | 要不要上地形 |
|---|---|
| e3、d6 的物资架（质心距地 250mm） | ⚠️ 要上 150mm 台阶后才够得着 |
| **d1、e8 台阶下的洞穴（70×70×50，向外开口）** | ✅ **地面就能探！** 我们已经设计了 `17_cave_probe` 洞穴探杆 |
| 中央高地焦点平台中心 | ⚠️ 要过桥或上坡到 300mm 高地 |

### 所以不上坡也能打

- **地面白块 a8 / h1 / c4 / f5 = 4 分**（半自动 ×1.5 = 6 分）
- **洞穴黄块 d1 / e8 = 8 分**（半自动 ×1.25 = 10 分）
- 合计够一个体面的成绩，**而且这三个位置我们都有对应机构（探杆）**。

### 上坡的最优路线

一定要上坡的话，**先攻 e1 / d8 的 150mm 矮坡**（爬升只有一半），上了台阶就能勾 e3 / d6 的物资架黄块。
**300mm 的中央高地和高台，是最后才考虑的。**

---

## 八、合规性：什么能买、什么不能买

### ✅ 可以（新生组）

| 项目 | 依据 |
|---|---|
| **电机、轮子换成表外型号** | 手册附录注 2：新生组的官方物资表是"**官方推荐**"，可以买其他物资 |
| 高倍率 18650 | 注 5：18650 本就要队伍自行选型购买，"仍属于物资表范畴" |
| M3 螺丝 / 螺母 / 扎带 | 注 3 反推：必要的紧固件、粘合剂本来就自备 |
| 粗硅胶线、电容、KF301 端子 | 属于线路辅材，不是"机器人物资" |
| 3D 打印件 | 手册明确允许自行设计 |

### ❌ 不可以

| 项目 | 原因 |
|---|---|
| **3S 电池（11.1V）** | 违反"单一供电、额定 ≤7.4V" |
| **两块电池组并联/串联** | 违反"单一供电" |
| 外挂升压模块给电机 | 供电装置数量判定问题，**别碰** |
| 成品机器人套件 | 手册 1.3 版专门加了"禁用成品机器人套件"的边界划分 |

### ⚠️ 别忘了

中期通过之后要买**官方无线继电器**（¥13.8/套）——检录必测的 10m 遥控断电。
中期**不买**是对的（注 6 原文："未通过中期测评的队伍无需购买"）。

---

## 九、采购清单（针对爬坡问题）

| # | 东西 | 规格（直接复制去搜） | 数量 | 预估价 | 解决什么 |
|---|---|---|---|---|---|
| 1 | 高倍率 18650 | `18650 动力电池 10A放电 3.7V` | 2~4 节 | ¥30~80 | 瞬时电流不够 |
| 2 | 硅胶软线 | `22AWG 硅胶线 多股软线 红黑` | 各 2m | ¥10 | 线阻压降 |
| 3 | 电解电容 | `470uF 25V 电解电容` | 4 个 | ¥5 | 瞬时掉压 |
| 4 | **橡胶轮** | `60mm 橡胶轮 TT马达 D轴 5.5mm` | 4 个 | ¥15 | **打滑（最有效）** |
| 5 | **1:120 减速马达** | `TT马达 1:120 单轴` | 8 个 | ¥30 | **扭矩不够（最有效）** |
| 6 | O 型圈 | `O型圈 硅胶 内径10mm 橡胶圈` | 1 包 | ¥5 | 麦轮辊子防滑（便宜方案） |
| | | | **合计** | **≈¥95~145** | |

**优先级：4 ≈ 5 > 1 > 2 > 3 > 6**

### 建议的下单顺序

1. **先买第 5 项（1:120 马达）+ 第 4 项（橡胶轮）** —— 这两个才是治本的。
2. 同时买第 1 项（动力电池）—— 这个不换，其他都白搭。
3. 第 2、3 项顺手带上（都是一次性小额）。

### 一个省钱提醒

**先凑齐"橡胶轮 + 1:120 马达"这一组，别的都可以慢慢来。**
如果预算实在紧，**只买橡胶轮（¥15）+ 动力电池（¥30）**，用第 1 档的助跑冲坡打，也能有一次机会上去。

---

## 十、今天/明天就能做的 5 件事

1. **量坡度**：手机水平仪贴在坡面上读角度。26.6° 是规范值。
2. **判类型**：上坡时轮子**转得快但车不动** → 打滑；**转得慢/发烫** → 没劲。拍照/录像记下来。
3. **查麦轮**：架空车，四轮往前转，看是不是"左两个朝前、右两个朝后"的 X 型。装错就重装。
4. **量电池**：万用表量满电电压（应 8.4V），再量爬坡瞬间（别低于 6.5V）。
5. **称车重**：整车多少克？**超过 600g 就别指望 1:48 上 300mm 坡了。**

把这 5 个数据记下来，就能确定买 4 还是买 5、要不要买 1。

---

## 附：给队友说的一句话版

> 官方那套 TT 1:48 马达 + 麦轮，爬 26.6° 的坡只在车重 0.6kg 以下才够用，我们整车 1.09kg，超了快一倍。麦轮在地胶上的摩擦系数刚好等于坡度的临界值，没有任何余量。硬件得改：换 1:120 减速马达加扭矩、换橡胶轮加摩擦，另外电池要换高倍率的。改完我重标速度参数。

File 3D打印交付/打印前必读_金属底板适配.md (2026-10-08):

# 打印前必读：配「欣薇 4 轮金属底板」的注意事项

> 针对你发来的那块 **25.5 × 15 cm 四轮金属底板折弯板（一体带马达孔，¥11.2）**。
>
> **⚠ 2026-10-04 整改（重要，覆盖了下面所有"要量板宽"的旧内容）**
> 上一版我把甲板做成**圆孔**去对金属板的孔 —— 这条路是错的：那块板手工折弯、
> 误差 ±0.5~1cm，它上面的孔还是给通用 TT 马达留的，跟我们根本不是一套。
> 你已经打出来的甲板孔对不上，**是我的设计失误，不是打错。**
>
> **现在改成：甲板上的安装孔全部换成「沿车宽方向的长圆槽」**
> （槽长 30mm、槽宽 4mm、中心 ±60）。效果是：
> - 螺钉在槽里随便滑，**金属板宽只要在 100~160mm 之间都能找到位置**
> - 就算板上一个能用的孔都没有，**扎带也能穿过槽把甲板绑上去**
> - **板宽一毫米都不用量了**，甲板现在可以直接打
>
> 下面正文里凡是写"必须量板宽 / 先打量规 / 改 MOUNT_Y"的地方，
> **一律作废**，保留只是为了留个记录。真正还要量的只剩「离地高度」一项。

---

## ⚠ 第 0 步：~~先打量板规~~ → **不打了**（2026-10-04 改）

~~新增了 3 个量规。先用它们量金属板，再决定打不打甲板。~~

**作废原因**：甲板上的孔已经从圆孔改成长圆槽，对板宽不再敏感。
板宽 100~160mm 这个范围里，几乎不存在装不上的情况（四个 TT 马达并排都要 ~120mm 了）。

`00_先打这个_量板规/` 里现在只有一样还有用：

```
gauge_height.stl     量板面离地高（24 / 28 两档）
```

**这一个建议打**（5 分钟）——它决定 `COL_H`（立柱高度）要不要从 15mm 改成 20mm。
判断标准在下面第二节第 2 项。

另外两个（`gauge_width_comb` / `gauge_hole_140`）已经用不上了，留着不碍事。

---

## 一句话结论

| 你的疑问 | 答案 |
|---|---|
| 图纸有问题吗？ | **没有**。几何、尺寸、重量都自洽，最大边 162mm 保证 220mm 床能打 |
| 和你这块金属板配得上吗？ | **配得上**，但只有**一个孔位**要现场对一下，见第三节 |
| 板上已有孔/焊接点，还需要你操心吗？ | 那些是给通用电机和传感器留的，**和我的件不是一套孔**。不影响，见第三节 |
| 需要做多个机械臂吗？ | **不需要**。两种方块是**同一个尺寸**，见第五节 |
| 今天打什么？ | **先打 3 件量板规（8 分钟）**，量完按顺序打，见第六节 |

---

## 一、你的底板 vs 我的图纸：逐项核对

```
你的金属底板     255 × 150 mm   厚约 1~1.5mm 折弯板   （卖家注明手工测量 ±0.5~1cm）
我的车设计       236 × 162 mm   （甲板长 × 车宽）
```

| 项目 | 你的板 | 我的件 | 结论 |
|---|---|---|---|
| 板长 255 | 255 | 甲板 236 | ✅ 甲板放上去**前后各余 9.5mm**，正好给保险杠和收集铲留位置 |
| 板宽 150 | 150 | 甲板 162 | ✅ 甲板两边各外悬 6mm，**靠 4 根立柱支撑**，不影响强度 |
| 车宽上限 195 | — | 168（含外观件） | ✅ 合规，余 27mm |
| 车长上限 290 | 255 | 236 | ⚠️ **见第二节第 3 条** |
| 马达孔 | 板上现成 | — | ✅ 你自己装电机，不关 3D 件的事 |

**这块板在我的设计里对应的位置**：`docs/02_机械结构与3D打印.md` 里的
**L0 层（0~60mm）—— "官方 4 轮金属底盘 + 4×TT 马达 + 4×60mm 麦轮"**。
3D 打印的甲板（`01` / `02` / `03`）是**架在它上面**的 L1 层，
用 4 根立柱（`04_column`）撑起，用来装储仓、电控托盘和机构。

> **所以甲板件必须打。** 金属板是承重的，3D 甲板是"设备层"，
> 两者是上下一叠的关系，不是二选一。

---

## 二、⚠️ 开工前先量三个数（拿卡尺或钢尺，2 分钟）

| # | 量什么 | 怎么量 | 为什么 | 量出来填这 |
|---|---|---|---|---|
| 1 | **板子实际宽度** | 最宽处（两翼之间） | 卖家注明 ±0.5~1cm 误差。甲板现在是**长圆槽**，板宽 ≥100 就够用 | ______ mm |
| 2 | **折弯后平面离地高度** | 板子平放在桌上，量平面到桌面的高度 | 我的立柱高 15mm，要求**底盘面距地约 30mm**（甲板才会落在 45mm 上，不压马达） | ______ mm |
| 3 | **整车总长** | 装上收集铲后，车头最前缘 → 车尾最后缘 | **规则红线 290mm**。板 255 + 铲伸出的部分要 ≤290 | ______ mm |

### 量完怎么判断

**第 1 项**：
- ≥ 148mm → 直接开打，不用改任何东西 ✅
- 140~147mm → 能打，但装配时立柱要往内挪，见第四节应急方案 A
- < 100mm → 甲板改用**扎带绕过板边缘**固定（不用改任何参数）
- 100~160mm → **什么都不用做**，长圆槽直接覆盖
- 旧的"改 `MOUNT_Y = 70` 为 60"的做法已作废（现在默认就是 60）：
  然后在 **仓库根目录**（`C:\Users\hp\WorkBuddy\CRTC`）执行下面这一行重生成，
  会出一套孔位更靠内的甲板。**其余件一律不动**

  ```
  C:\Users\hp\.workbuddy\binaries\python\envs\default\Scripts\python.exe mechanical/gen_parts.py
  ```

  ⚠ 两个坑：
  1. 别直接敲 `python gen_parts.py` —— 脚本在 `mechanical/` 里，会报找不到文件
  2. 别用普通 python —— 它没装 numpy，会报 `No module named 'numpy'`。
     上面那串长路径就是装了 numpy 的那个 python

  （重生成只改甲板孔位，其余 24 个件几何一字不动，之前打的件不会白打）

**第 2 项**：
- 约 28~32mm → 完美，立柱 15mm 刚好
- 明显低于 28mm → 甲板会压到 TT 马达减速箱顶部（马达壳会挤变形、卡齿轮）。
  解决办法：打印时把立柱拉高。改 `COL_H = 15.0` → `20.0` 重跑
- 明显高于 32mm → 车整体变高，只要总高仍 ≤210mm 就没问题

**第 3 项**：
- ≤ 290mm → 合规 ✅
- 285~290mm → 卡在红线上，**建议把收集铲往后挪 10mm 再固定**（孔位留了余量）
- > 290mm → 必须处理：把铲往后挪，或者把金属板前端多出的那 9.5mm 磨掉/切掉

> **为什么第 3 项最容易踩**：我的甲板只有 236mm，但你的板子 255mm，
> 多出的 19mm 如果全留给收集铲往前伸，铲再伸出 90mm 就爆了。
> 装配时**让铲的后半段压在金属板上**，别整个往前悬空。

---

## 三、甲板怎么固定到金属板（2026-10-04 重写：不再有"必须对上的孔"）

甲板上现在**没有安装圆孔**，只有 4 条长圆槽：

```
位置：每段甲板 2 条（x = 14 和 x = 114），共 4 条
槽：  沿车宽方向，中心 ±60，槽长 30mm（可调范围 ±45 ~ ±75），槽宽 4mm
```

**为什么这么做**：±15mm 的滑动量，覆盖了几乎任何一块能塞得下四个 TT 马达的底板。

### 装的时候怎么办（按优先级试）

1. **先穿螺钉**：M3 螺钉 + M3 平垫从槽里穿下去。槽是通的，所以**必须加平垫**（或加大垫片），
   不然螺母没有着力面。滑到最合适的位置拧上就行
2. **板上没孔/不想钻孔 → 用尼龙扎带**：标准 2.5mm 扎带刚好能从 4mm 的槽里穿过去。
   扎带绕过金属板的长条槽（或整块板），捆住立柱。**这是推荐办法，比螺丝还抗震**
3. **介于两者之间**：金属板是铝/铁的，用 **M3 自攻螺丝**直接攻进去也行。
   1.5mm 板很好攻，攻之前用样冲打个定位眼防钻头跑偏
4. **临时验证**可以垫 3M 双面胶 + 甲板自重，但上场前一定要换成螺钉或扎带

> ⚠️ 不管用哪种，**装完把车架空、四个轮子悬空，用手摇一摇甲板**。
> 甲板晃 = 后面所有机构（夹爪、储仓、视觉）的定位全不准。
> 这一步 10 秒钟，能省你两天。

---

## 四、应急：三个常见情况怎么办

### 情况 A：~~板宽不够，立柱孔落在板外~~ → **不会再发生了**

改成长圆槽之后，槽的可调范围是 **±45 ~ ±75mm**，覆盖板宽 100~160mm。

真要是遇到极端情况（螺钉滑到槽最内端还是够不着金属板），
**直接用扎带穿过槽把甲板绑到板上**，不用改脚本、不用重打。

（旧办法 —— 改 `MOUNT_Y` 再重跑脚本 —— 已经不需要了。长圆槽比它好用，也更省时间。）

### 情况 B：甲板被马达顶住，装不下去

同上，改 `COL_H = 15.0` → `20.0`，重跑脚本，重打 4 根立柱（很小，10 分钟）。

### 情况 C：整车超 290mm

别急着改图纸。**先试着把收集铲往车尾方向挪**——
我的铲和保险杠孔位都留了前后 ±10mm 的余量。
实在不行，金属板前端多出的 9.5mm 用角磨机/钢锯切掉（铝板很好切）。

---

## 五、为什么不需要多个机械臂

你说"一个机械臂可能抓不住，不排斥多个"——这个担心可以放下，原因很具体：

**手册里两种道具是同一个尺寸：**

| 道具 | 颜色 | 尺寸 | 分值 | 数量 |
|---|---|---|---|---|
| 能量单元 | 白色 | **30mm 立方体**（V1.4） | 1 分 | 18 个 |
| 能量核心 | 黄色 | **30mm 立方体**（V1.4） | 4 分 | 5 个 |

**两种方块一模一样大，只是颜色不同。** 所以"抓不同方块"这个前提下，
**根本不需要换夹爪、更不需要第二个臂**——一个夹爪通吃 23 个道具。

真正让"抓得住"的，不是臂的数量，是这三件事（都已经做进去了）：

1. **机械对中**：V 型喇叭口（张开 60°）+ 双微动开关，
   把歪着撞进来的方块导流回中间，400ms 窗口内两个开关都压到才算对中成功
2. **喉口 46.4mm**：不是 30mm。因为方块转 45° 时投影宽 42.4mm，
   加上车身抖动 ±3mm，留 12mm 余量是必须的
3. **夹爪平放打印**：这是踩过坑的——竖着打省支撑，但夹紧时**从层间裂开**了

### 加第二个臂的真实代价（如果你还是想加）

| 项 | 代价 |
|---|---|
| 重量 | 每个臂至少 3 个舵机 + 结构件 ≈ 150~200g，限重 2.0kg 余量会告急 |
| 供电 | MG995 堵转实测 1.2A，再加一组会让 5V 直接塌，单片机复位 |
| 考核 | 手册里"舵机多项"是按舵机数量算分的，5 个舵机（1×MG995 + 3×SG90 + 备用）已经在这个考核线上 |
| 时间 | 要重新设计、重新打印、重新验证，**今天肯定出不来** |

**我的判断：单臂 + 机械对中是对的路线。** 半自动那套一键宏已经能覆盖
"定点取块 → 抬起 → 入仓"，全自动再叠一个调度器就够了。
省下的时间拿去做**对中成功率**和**储仓不掉块**，收益大得多。

---

## 六、今天照打清单

> ✅ **2026-10-04 起顺序恢复正常：甲板可以直接打，不用再等任何测量结果。**
> 唯一还建议先打的工装是 `gauge_height.stl`（5 分钟，决定立柱要不要加高到 20mm）。

| 序号 | 打什么 | 在哪 | 文件 / 件数 | 约重 | 大约用时 |
|---|---|---|---|---|---|
| **0** | 离地高度规（可选） | `00_先打这个_量板规/` | 1 文件 / 1 件 | <5 g | 5 分钟 |
| **1** | **甲板 + 立柱（现在就能打）** | `01_底盘必打/` | `01_deck_front` `02_deck_rear` `03_deck_splice` `04_column`×4 | 81 g | 4~5 小时 |
| **2** | 底盘其余 4 件 | `01_底盘必打/` | 4 文件 / 5 件 | ≈ 43 g | 2~3 小时 |
| **3** | 收集与储仓 | `02_收集与储仓/` | 8 文件 / 12 件 | 91 g | 5~7 小时 |
| **4** | 机械臂与机构 | `03_机械臂与机构/` | 9 文件 / 12 件 | 40 g | 4~6 小时 |
| **5** | 备件 | `05_备件多打一份/` | 5 文件 / 5 件 | ≈ 15 g | 2 小时 |
| **6** | 外观套件 | `04_外观套件/` | 14 文件 / 14 件 | 72 g | 6~8 小时 |

> ⚠️ **你已经打出来的那块旧版前段甲板（圆孔版）建议不要再用了**，
> 换新的长圆槽版。原因：圆孔版是按"板宽 ≥150"假设打的，
> 你这块板实际多宽我没拿到，继续用它，孔对不上的概率很高。
> 换新的长圆槽版只是多花 4 小时料，比重做整车便宜太多了。
> 那块旧的别扔，当**试打件**用：拿它确认 A1 mini 的尺寸精度、
> 提前试试层高 0.20 / Brim 8mm 好不好撕 —— 它已经值回票价了。

### 三件打印完必做的加工（不做等于白打）

1. **收集铲前缘倒 30° 斜面**（`05_scoop_floor`）
   —— 用锉刀，倒角长约 10mm。不倒的话 6mm 厚的直边只会把方块推走，
   **这是整个收集机构成败的关键一步**
2. **所有 M3 孔用 φ3.2 钻头通一遍** —— PLA 会缩，孔径实际偏小 0.2mm
3. **平板件一律平放打印** —— 侧着打层间强度掉一半，夹爪就是这么裂的

---

## 需要我改的时候，说一句话就行

你不用自己动脚本。告诉我量出来的数，或者说"把 MOUNT_Y 改成 60"，
我改完重跑脚本、重新生成 STL 和图纸，直接给你文件。
图纸集（`图纸集_结构件.html`）里有每个件的尺寸图和装配要点。

**本文件对应图纸版本**：**长圆槽版 v2（2026-10-04）** —— 甲板安装孔改成长圆槽
（`MOUNT_Y = 60`、`MOUNT_SLOT_H = 15`、`MOUNT_SLOT_W = 4`），对金属板宽度不再敏感。
生成脚本 `mechanical/gen_parts.py`。

> 需要改的时候不用你自己动脚本，跟我说一声就行。
> 另外：**同一版本现在会额外生成一套 DXF**（`mechanical/dxf/`，
> 已复制到 `D:\WorkBuddy\CRTC交付\给机械队友_CAD包\`），
> 你机械组的队友拿去能在 SolidWorks / Fusion 里直接拉伸改图。

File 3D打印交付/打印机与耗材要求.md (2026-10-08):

# 打印机与耗材：有什么要求？

> 一句话结论：**只要是一台普通的 FDM 打印机（打 PLA 的那种），床 ≥ 200×200mm，就能打。**
> 耗材买 **PLA+（增韧），1.75mm，两卷 1kg（一深一浅）**，大约 ¥100~160。
> 下面写清楚为什么，以及哪些情况要停下来问我。

---

## 0. 先确认一件事：你那台机器能不能打？

照这 4 条打勾，**全勾上就开工**，有一条不对就先别打：

| # | 检查 | 怎么确认 | 我们要求的下限 |
|---|---|---|---|
| 1 | **是 FDM 机**（喷头挤丝那种），不是光固化 | 看有没有一卷丝挂在机器上。有丝 = FDM ✅ | **必须是 FDM** |
| 2 | **打印床最短边 ≥ 170mm** | 看机器铭牌，或量平台 | 我们最大的结构件 128×162mm |
| 3 | **耗材直径 1.75mm** | 看机器上挂的料盘标签，或进料口 | 1.75mm（99% 的机器都是） |
| 4 | **热床能到 60℃** | 屏幕上看温度设置 | ≥ 60℃ |

> 常见机器对照：创想三维 Ender-3 / Ender-3 V2 / V3（220×220）✅、
> 拓竹 Bambu A1（256×256）✅、Bambu A1 mini（180×180）✅ 勉强够、
> Prusa MINI（180×180）✅、纵维立方 Anycubic Kobra（220×220）✅。
> **150×150 以下的迷你机打不了甲板**——别硬试，告诉我，我把甲板再切一刀分四段。

### ⚠️ 光固化机（LCD / SLA / DLP）绝对不能打这些件

学校创客空间如果有那种"用液体树脂、紫光照"的机器，**不要拿去打结构件**。三个致命问题：

1. **树脂件脆得像饼干**——比赛车会撞墙、会从 180mm 摔下来（规则明确要求跌落后不掉件），树脂件一撞就碎。
2. **床太小**——光固化机常见床只有 120×70mm，我们的甲板 162mm 根本放不进。
3. **会继续固化变形**——树脂件打完放几天会翘，孔位就变了。

光固化机适合打手办，不适合打结构件。

---

## 1. 耗材买什么

### 直接下单清单（照抄就行）

| 东西 | 规格 | 数量 | 参考价 | 用途 |
|---|---|---|---|---|
| **PLA+（增韧）** 深色 | 1.75mm / 1kg，**黑**或**深灰** | 1 卷 | ¥50~80 | ① ② ③ 全部结构件 |
| **PLA+（增韧）** 亮色 | 1.75mm / 1kg，**橙**或**白** | 1 卷 | ¥50~80 | ④ 外观套件（最后打） |
| 3mm 钻头（或麻花钻） | φ3.0 / φ3.2 | 1 支 | ¥5 | 打印件孔径会缩，扩孔用 |
| 铲刀 / 刮刀 | 通用 | 1 把 | ¥10 | 取件用，别用手掰 |
| 固体胶棒 | 普通文具胶棒 | 1 支 | ¥5 | 床 adhesion 差时涂一层 |
| M3 圆头螺丝 + 螺母 | M3×8、M3×12、**M3×30** | 各 10 套 | ¥15 | 装配（立柱 22mm + 甲板 4mm = 26mm，要 **M3×30**） |

**合计约 ¥140~180**（只买一卷深色的话 ¥60~90）。

### ⚠️ 关于预算，有句话要说清楚

`docs/09` 的成本表里 PLA 只记了 **¥15**——那是按"一卷 ¥60，我们只用掉约 1/4"算的**原料价**，
规则也是这么认定的（"以购买发票为准仅将其原料价格计入制造成本"）。

但**你实际掏的钱是整卷的价**：

```
官方物资表（已买）        ¥353
补买件（微动开关/线材等）  ¥62
────────────────────────────
小计                     ¥415   ← 这就是之前跟你说的数
+ 耗材（实际现金）       ¥100~160  ← 之前没算进来
────────────────────────────
实际现金支出             ¥515~575
```

**报销上限 ¥400，超出部分要自付。** 想压下来就**先只买一卷深色**（¥50~80），外观件那卷等中期考核通过后再说。

### 为什么是 PLA+ 而不是普通 PLA

| | 普通 PLA | **PLA+（也叫 PLA Pro / 增韧 PLA）** |
|---|---|---|
| 价格 | ¥40~60 | ¥50~80（贵 10 块） |
| 刚度 | 够 | 差不多 |
| **抗冲击** | **脆，摔一下就裂** | **韧很多，摔了弹得回来** |
| 打印难度 | 简单 | 一样简单（温度高 5~10℃） |

比赛车会撞墙、会被撞、要过 180mm 跌落测试。**这 10 块钱差价是最值的保险。** 买它。

### 品牌怎么选

**别买 9.9 包邮的杂牌**——丝径忽粗忽细会堵头，堵一次你就要拆喷头半小时。

够用且常见的：三绿 SUNLU、易生 eSUN、Polymaker、创想三维 Creality、拓竹 Bambu。
按 ¥50~80/kg 这个价位买就行，不用追贵的。

### 两种颜色怎么用

单色打印机也能做出双色效果——**分两盘打，不要中途换料**：

```
结构件（①②③）→ 深灰或黑色    耐脏、显专业、划痕不明显
外观件（④）    → 橙色或白色    场上好认，队友一眼能找到自己的车
```

⚠️ 颜色只影响好不好看，**不影响能不能跑**。如果只买得起一卷，就买深色一卷，全打深色，外观件以后再说。

---

## 2. 买多少够？（算给你看）

我们实测：

```
50 个件，实体总重       324 g
+ 25% 废品/裙边/支撑     ≈ 405 g
+ 备件批次⑤（多打一份）  ≈  25 g
────────────────────────────────
实际耗材消耗             ≈ 430~480 g
```

**一卷 1kg 够打完全部。买两卷是因为**：

1. 你要打两种颜色（深色一卷 + 亮色一卷）
2. **新手第一次打必定会废几件**——翘边、堵头、取件掰断。留 30% 余量心里不慌
3. 万一设计要改（比如你量完底板发现孔位要挪），重打几个大件就吃掉半卷

> 一卷 1kg 的丝大约能打 330 米。我们全部件加起来用不到半卷，余量很足。

---

## 3. 打印机侧的要求（给操作的同学看）

| 项 | 要求 | 不达标的后果 |
|---|---|---|
| **喷嘴直径** | **0.4mm**（标配） | 0.2 太慢（一个甲板 8 小时）；0.6+ 打不出 M3 孔的细节 |
| **喷嘴温度** | PLA：200℃（第一层 205）；PLA+：205~215℃ | 温度低了层间粘不住，一掰就分层 |
| **热床温度** | 60℃（第一层 65℃） | 低于 55℃ 大件会翘边脱落 |
| **首层速度** | 20~25 mm/s | 快了粘不住床 |
| **冷却风扇** | **首层关，之后 100%** | 首层开风扇 = 必翘 |
| **床要调平** | 打印前必须做 | 这是新手 80% 失败的原因 |

> 这些参数在 `切片与打印操作手册.md` 第 4 节有完整版，照抄即可。

---

## 4. 三个新手必踩的坑（提前说，省两小时）

**① PLA 怕热。**
60℃ 就开始软。打完的件**别放窗台晒、别放车里、别放在暖气片旁边**。夏天赛场如果暴晒，车会慢慢变形。这是 PLA 唯一的硬伤，没法解决，只能避开。

**② 层间结合是最弱的地方。**
3D 打印件是"一层一层叠"的，层与层之间的结合力比层内弱得多。所以**摆放方向决定强度**：

- ❌ 夹爪指竖着打 → 夹东西时正好从层缝裂开（我们第一版就这么废的）
- ✅ **平躺着打** → 受力方向和层纹平行，扛得住

手册第 3 节写了每个件该怎么摆，照着做。

**③ 孔径一定会缩。**
打印出来的 M3 孔实际会小 0.2~0.3mm，螺丝插不进。**这是正常的，不是设计错了。**
用 3mm 钻头手动扩一下就行，千万别以为"孔打小了"去改模型。

---

## 5. 环境要求（容易被忽略）

| 项 | 要求 |
|---|---|
| 桌面 | 机器要放**水平且稳固**，打印时会震，桌子晃会导致层错位 |
| 通风 | PLA 气味很小，但别在密闭宿舍打一整夜 |
| 电源 | 打印机功率 200~350W，别和电热水壶插一个插线板 |
| 人 | **前 5 分钟必须在旁边盯着首层**，翘边了立刻停，晚了就白打一整件 |

> 一个甲板要打 4~6 小时。**不要半夜开始打然后去睡**——半夜堵头/翘边，早上起来就是一坨废塑料。
> 白天开始打，中途看几次。

---

## 6. 你现在要做的（三步，10 分钟）

1. **看机器铭牌**，把型号告诉我（或拍张照片发我），我判断能不能直接打
2. **量一下床**（能打的最大方块边长），≥200mm 就没问题
3. **买耗材**：PLA+ 深色 1 卷 + 亮色 1 卷（急的话先只买深色一卷，够打完 ①②③）

> 如果你们实验室**已经有 PLA 丝**，先问一句是什么料、放了多久。
> **开封超过半年且没密封保存的 PLA 会受潮**，打出来表面起疙瘩、层间粘不住。
> 受潮的料 60℃ 烘 4 小时能救回来，或者直接买新的（一卷才 50 块，比重打一遍划算）。

---

## 附：如果床不够大怎么办

| 床尺寸 | 情况 | 怎么办 |
|---|---|---|
| ≥ 220×220 | 理想 | 直接打，一床能摆 3~5 件 |
| 180×180 | 能打 | 甲板正着放（128×162 都 < 180）✅，但一次只能摆 1~2 件，慢 |
| 150×150 | **打不了甲板** | 告诉我，我把甲板切成 4 段（现有是前后 2 段） |
| ≤ 120 | 别用这台 | 换机器 |

甲板为什么要分段：整块 236×162mm 超床，所以切成**两段各 128mm**，接缝处**重叠 20mm**（128 + 128 − 20 = 236）。
接缝下方垫 `03_deck_splice`（60×60 搭接板），**M3×8 螺丝从下往上穿**。这个件别漏打，漏了甲板就是两片。

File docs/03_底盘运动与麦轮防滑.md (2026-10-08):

# 底盘运动与麦轮防滑

## 功能描述

让两个 PS2 摇杆变成四个轮子的转速，并且**在白色地胶上不打滑、在坡上不溜车**。
这是全车技术含量最高的一块，也是我们在 09-23 ~ 09-26 连着改了四版的地方。

代码位置：`firmware/Core/Src/mecanum.c`（解算 + 防滑）、`motor.c`（输出层）、
参数全部集中在 `firmware/Core/Inc/config.h`。

---

### 2026-09-19 · 麦轮运动学：纸上先推一遍

坐标约定（写死在 `mecanum.h` 里，全工程统一）：

```
x = 车头方向（前为正）
y = 车体左侧（左为正）
ω = 逆时针为正（俯视）
轮序：0=LF 左前  1=RF 右前  2=LB 左后  3=RB 右后
```

X 型麦轮的逆解（推导过程见代码注释）：

```
w_LF = ( vx - vy - (a+b)·ω ) / R
w_RF = ( vx + vy + (a+b)·ω ) / R
w_LB = ( vx + vy - (a+b)·ω ) / R
w_RB = ( vx - vy + (a+b)·ω ) / R
```

其中 a = 半轴距 = 0.090m，b = 半轮距 = 0.068m，R = 轮半径 = 0.030m。

**我们先用三个特例自检，再写代码**（这一步救了我们至少半天）：

| 动作 | 期望 | 代入公式 |
|---|---|---|
| 纯前进 vx>0 | 四轮同号同值 | 四轮都是 +vx/R ✓ |
| 纯左移 vy>0 | 对角同号 | LF=−、LB=+、RF=+、RB=− ✓ |
| 纯逆时针 ω>0 | 左轮退右轮进 | LF=−、LB=−、RF=+、RB=+ ✓ |

正解（给将来的里程计用）也一起写了，先用不上但保留接口：

```
vx = ( w1 + w2 + w3 + w4 ) · R / 4
vy = (−w1 + w2 + w3 − w4 ) · R / 4
ω  = (−w1 + w2 − w3 + w4 ) · R / (4·(a+b))
```

### 2026-09-21 · 单电机先转起来：确认 PWM 频率

用 TIM4 四通道输出 PWM。**频率定为 10kHz**，理由：

- 太低（< 5kHz）：电机有啸叫，而且低速时转矩脉动明显
- 太高（> 20kHz）：DRV8833 的开关损耗上升，便宜模块会发热
- 10kHz 是个不啸叫、也不发热的甜点

CubeMX 配置：`TIM4` PSC = 0、ARR = 7199 → 72MHz / 7200 = 10kHz。
改了 CubeMX 的分频要同步改 `motor.c` 里的 `MOTOR_PWM_PERIOD`，否则占空比全部错。

### 2026-09-22 · 四个电机全转：踩到 nSLEEP 悬空

**现象**：PWM 波形用万用表量到了（有电压变化），但电机一动不动。

**排查**：量 DRV8833 的 `nSLEEP` 引脚 —— **悬空**。
DRV8833 的 nSLEEP 是低电平休眠，几块钱的模块经常把它引出来但不默认上拉。
悬空时芯片处于随机状态，多数时候就是休眠。

**解决**：飞一根线把 nSLEEP 接到 VCC（我们接的是改造后的 5V，见 `04` 板块）。

> 这个坑的特点是"看起来像驱动烧了"，新手很容易直接换模块。
> 我们把它写进了 `硬件接线与焊接指南.md` 的故障速查表第一条。

### 2026-09-23 · 麦轮解算 v1：横移时车自己转圈

**现象**：推纯横移（左摇杆只往左右打），车确实往左走，但**同时在缓慢自转**，
走 1 米能偏 30° 以上。推纯前进反而正常。

**原因**：我们第一版对每个轮单独做了限幅：

```c
// v1（错）
for (i=0;i<4;i++) if (wheel[i] > 1.0f) wheel[i] = 1.0f;
```

纯横移时四轮的**绝对值相等**，所以看不出问题。
但因为有 `SPEED_GAIN_STRAFE = 0.80` 而 `SPEED_GAIN_YAW = 0.45`，
只要操作手的手有一点点抖（摇杆不可能完全只动一个轴），
ω 分量就会让某些轮先撞到 100% 上限被截掉，
**截断之后四轮的合成速度矢量方向就不再是纯横移了** —— 于是车画弧。

### 2026-09-24 · 矢量归一化限幅：本周期最重要的一次改动

**改法**：算出四轮绝对值的最大值，如果超过 1 就**整体等比缩放**：

```c
// v2（对）
float mx = max(|w[0]|,|w[1]|,|w[2]|,|w[3]|);
if (mx > 1.0f) { float k = 1.0f/mx; for(i) w[i] *= k; }
```

这样速度矢量的**方向严格保持**，只是整体变慢一点。
慢一点是可接受的，方向错了是不可接受的 —— 尤其在 2400×2400 的场地里，
方向错 10° 走 2 米就偏 350mm，会直接错过一个方块。

**效果**：横移偏航从 30°/m 降到 **< 3°/m**【待回填：实测】。

这个处理几乎不花成本（6 行代码），但它是"新手车"和"能打的车"的分水岭。
我们把它写进代码注释时特意写了长注释，因为**这一步最容易被漏**。

### 2026-09-25 · 死区补偿：解决"小油门不动、半油门窜"

**现象**：摇杆推 20% 车不动，推到 50% 突然往前窜一下。

**原因**：TT 马达 + DRV8833 有**静摩擦死区**。占空比低于约 18% 时电机转矩克服不了
齿轮箱静摩擦，完全不转；一旦超过，车就以一个不小的初速度起步。这是典型的开环系统特性。

**改法**：把 0~1 的速度映射到 `DEADZONE ~ 1` 的占空比：

```c
duty = MOTOR_DEADZONE + mag * (1.0f - MOTOR_DEADZONE);
```

`MOTOR_DEADZONE` 默认 0.18，实测范围 0.12 ~ 0.26（取决于地面脏不脏、电池电量）。

**副作用与处理**：加了死区之后，速度为 0 附近会有阶跃。
我们在 `chassis_ramp()` 里加了 `if(|cur| < 0.001) cur = 0`，消掉 0 附近的抖动。

### 2026-09-26 · 加速度斜坡：起步不打滑了

**现象**：满油门起步的瞬间，四个轮子空转"吱"一下，车反而慢半拍才动。

**分析**：麦轮的辊子是塑料的，和地胶的接触是**小面积线接触**，
比普通橡胶轮容易打滑得多。突加占空比 → 瞬时转矩突破静摩擦 → 打滑 →
轮子转得比车快 → 车反而没怎么动。

**改法**：限制速度变化率（斜坡限幅），让轮子始终工作在滚动摩擦区：

```c
float lim = (加速? ACC_UP : ACC_DOWN) * dt;
d = clamp(target - cur, -lim, +lim);
cur += d;
```

加速和减速用**不同的上限**（`ACC_UP = 3.0`、`ACC_DOWN = 6.0` / 单位：归一化速度每秒）。
起步慢一点、刹车快一点，既防滑又符合操作直觉。

**调参手感对照**（写进 config.h 了）：

| 现象 | 改哪个 | 方向 |
|---|---|---|
| 起步轮子空转、车抖 | `CHASSIS_ACC_UP` | 调小 |
| 起步肉、反应慢 | `CHASSIS_ACC_UP` | 调大 |
| 松摇杆滑行很远、冲过目标 | `CHASSIS_ACC_DOWN` | 调大 |

另外加了**起步助力（kick）**：从静止跨过阈值时额外叠 12% 占空比，120ms 内线性衰减。
这是为了克服静摩擦的"那一下"，比单纯调大死区温和得多 —— 死区调大会让低速控制变粗糙。

### 2026-09-24（补）· 高速限自转：防止甩尾

**现象**：边前进边自转时，整车会"甩"一下，方向突然变。

**原因**：麦轮靠四轮的差速合成转向。高速行进时叠加自转，
某些轮会进入反向大电流区，瞬时打滑 → 合成矢量突变。

**改法**：把 ω 的上限做成线速度的函数：

```c
|ω| ≤ YAW_LIMIT_BASE − YAW_LIMIT_K · |v线|
```

`BASE = 0.90`、`K = 0.60`：静止时可以全速自转（0.90），
全速前进时只剩 0.30 的自转能力。这符合物理直觉，也符合比赛实际 ——
高速冲的时候本来也不该大幅转向。

### 2026-10-12 · 电池电压补偿：两局之间速度要一致

**现象**：同一套参数，刚充好电时车跑得挺好，第二局（电池掉到 7.0V 左右）明显变慢，
操作手会觉得"车坏了"，其实就是电压掉了。

**改法**：测电池电压，占空比按比例补回来：

```c
g_vcomp = VBAT_NOMINAL / vbat;       // 7.40 / 7.00 = 1.057
duty *= g_vcomp;                      // 上限 VBAT_COMP_MAX = 1.25
```

分压电路是 20k + 10k（比值 3.0），接 PB1 / ADC1_IN9，
采样周期 200ms 并做了一阶滤波（α=0.2），避免电机启停时的电压毛刺导致占空比抖动。

同时加了低电压报警：低于 6.60V 时 LED 从 1Hz 慢闪变成 5Hz 快闪 + 蜂鸣器响。
**18650 过放会永久损坏**，这个报警是保护电池的，不是装饰。

### 2026-10-14 · 坡道防滑撑地块（进阶功能）

2 号机在地面活动，遇到坡道（26.6°）时麦轮会打滑。
我们加了一个 SG90 驱动的"撑地块"：

- 平地上收起，离地 15mm
- 上坡前放下，橡胶垫（自行车内胎剪的）压地

原理是**增加正压力**从而提高最大静摩擦。要注意的是它不能"顶起车"
（那会让驱动轮离地反而更糟），而是**轻触地面提供额外摩擦**。

`22_ramp_anchor.stl` + `config.h` 里的备用舵机角度控制。
【待回填：上坡实测成功率】

### 为什么我们没有做编码器闭环

**没有做，但要说清楚为什么**（这是答辩时会被问的）：

1. 官方物资表里的 TT 马达是**单轴 1:48 无编码器款**，
   要闭环得另外买带编码器的马达（约 +12 元/个 × 8 = 96 元），超出成本预算。
2. 编码器要占用 TIM2/TIM3 的输入捕获通道，而我们的 TIM2 已经给舵机了。
3. 时间上，新手在一周内调通 4 路 PID 的风险很高。

**但代码里留了口子**：`config.h` 的 `USE_ENCODER` 打开后 `motor.c` 会切到 PID 闭环，
`USE_IMU` 打开后可以做航向保持。如果中期考核后有时间和预算，这是第一个要补的升级。

---

## 参数定稿表（2026-10-17）

| 宏 | 值 | 备注 |
|---|---|---|
| `MOTOR_DEADZONE` | 0.18 | 地面脏时调到 0.24 |
| `SPEED_GAIN_FORWARD` | 0.85 | |
| `SPEED_GAIN_STRAFE` | 0.80 | 麦轮横移效率天生低 |
| `SPEED_GAIN_YAW` | 0.45 | 给小，防打滑 |
| `CHASSIS_ACC_UP` | 3.0 | 打滑严重降到 1.5 |
| `CHASSIS_ACC_DOWN` | 6.0 | |
| `MOTOR_KICK_DUTY` | 0.12 | |
| `MOTOR_KICK_MS` | 120 | |
| `YAW_LIMIT_BASE / K` | 0.90 / 0.60 | |
| `VBAT_NOMINAL / LOW` | 7.40 / 6.60 | |
| `CHASSIS_V_MAX / W_MAX` | 0.60 / 4.00 | 【待回填：掐表实测】 |

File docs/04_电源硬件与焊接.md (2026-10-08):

# 电源、硬件与焊接

## 功能描述

把一块 7.4V 电池分配成"电机动力"和"5V 逻辑/舵机"两路，并且满足手册对
**唯一供电模块**、**无线继电器遥控断电**的强制要求。完整引脚表与焊接点位见
`docs/硬件接线与焊接指南.md`，本板块只记录决策过程与踩过的坑。

---

### 2026-09-18 · 电源树设计：先读规则再动手

手册 3.3.2 里最容易理解错的一句：

> 每台机器人仅允许安装 1 个供电模块，且供电模块额定电压不超过 7.4V。
> 供电模块定义为**有且仅有一个输出接口**的供电装置。

我们的理解（并在 Q&A 文档里确认口径）：

- 2 节 18650 **串联** → 标称 7.4V、满电 8.4V → 符合"额定电压 ≤ 7.4V"
- 电池盒自带的那**一对线**就是唯一输出接口
- 所有分支必须在电池**之后**分，不能在电池盒里做成两路独立输出

电源树：

```
18650×2 (7.4V)
   └─ 无线继电器 (IN 接电池 / OUT 接整车)
        └─ 节点 P
             ├─ DRV8833 ×2 的 VM        (7.4V 直供)
             └─ Mini 降压 → 5V
                  ├─ STM32 的 5V 脚
                  ├─ MG995 ×1
                  └─ SG90 ×3
```

### 2026-09-19 · 继电器取电位置：一个能直接毁掉整局的坑

我们一开始把继电器串在了电池和整车之间，线圈也从 OUT 侧取电。
按断电遥控器的瞬间，继电器自己也没电了 —— **再也合不上，车永久断电**。

正确接法：`IN+ / IN-` 接**电池直出**，`OUT+ / OUT-` 接整车。
继电器控制的是"整车"，不是"自己"。这条写进了接线指南的 1.3 节。

另外记录规则细节：手册说检录时会检测遥控断电功能，**检测无误后参赛队需要向裁判上交断电遥控器**，
比赛结束后取回。所以继电器和遥控器要在检录前就装好、测好，别指望现场调。

### 2026-09-22 · DRV8833 逻辑电源改造（必做）

DRV8833 芯片的 `VCC`（逻辑电源）规格是 **1.8 ~ 7V**，`VM`（电机动力）可以到 10.8V。
我们电池满电 8.4V。

用万用表蜂鸣档量了几块钱的红色模块，发现 `VCC` 和 `VM` **是通的** ——
厂家用一颗 0Ω 电阻把 VCC 直接接到 VM 上了。这意味着长期运行时 VCC 会被 8.4V 超规格供电。

**改造**：切断 VCC 与 VM 之间的铜箔（或拆掉那颗 0Ω），把 VCC 单独飞线到 5V。
改完再量一次确认两者不通。

> 这个改造 5 分钟能做完，但不做的话驱动芯片在比赛中后期失效的概率不低。
> 而且芯片失效的表现往往是"电机时转时不转"，排查起来非常痛苦。

### 2026-09-29 · MG995 上电：5V 塌陷导致单片机复位

**现象**：单独给 SG90（小舵机）供电一切正常；一把 MG995 接上、让它转动，
STM32 立刻复位（串口输出的 boot 信息重新打一遍）。

**测量**：MG995 启动/堵转电流实测能到 **1.2A**（用钳形表在 5V 线上量的，
万用表串进去会因为内阻太大测不准）。

**原因链**：
1. 杜邦线线芯只有约 0.2mm²，1A 电流下的压降非常可观
2. Mini 降压模块瞬态响应跟不上，5V 瞬间跌到 4.3V 以下
3. STM32 板载 AMS1117-3.3 的输入低于 4.5V 就撑不住 3.3V 输出 → 单片机复位

**解决（按做的顺序）**：

| # | 措施 | 效果 |
|---|---|---|
| 1 | 在 5V 汇流点并 **470μF/16V 电解 + 0.1μF 瓷片** | 复位次数明显减少，但没根治 |
| 2 | 5V/GND 主干换成 **0.5mm² 硅胶线**（弃用杜邦线做电源） | 基本解决 |
| 3 | `SERVO_SPEED_DPS` 从 240 降到 200，限制舵机动作速度 | 峰值电流下降 |
| 4 | `arm.c` 改成**串行序列器**，同一时刻只有一个舵机在动 | 彻底解决 |

第 4 条是设计层面的改动，值得展开说一下：

> 我们原来的 `Arm_Start()` 是"同时给所有舵机下发目标角度"。
> 四个舵机一起启动 = 峰值电流叠加。改成序列器后，
> 一个舵机到位 → 等 N 毫秒 → 再动下一个。
> 代价是一个完整取块动作从 0.6s 变成约 1.2s。
> **我们接受这个代价**：比赛 5 分钟，慢 0.6s 不影响拿几个块；
> 但现场复位一次，可能直接丢掉一整局。

### 2026-09-30 · 转接板：从面包板到洞洞板

前期用面包板验证功能，但手册 3.3.3 明确写：

> 线路设计时建议采用集成电路板的方式，单一使用杜邦线易出现连线脱落的情况。

而且结构强度检测是从 180mm 高处**自由跌落** —— 面包板上的杜邦线必掉。

于是花了一个晚上焊了一块 7×9cm 洞洞板：

- STM32 用 **2×20 排母**插装（方便拔下来烧录）
- 电机 8 路（PWM×4 + DIR×4）、舵机 4 路、PS2 6 路、限位开关 2 路全部用排针引出
- 5V 和 GND 在板背面用 0.5mm² 导线做主干（洞洞板的铜箔带不动 1.5A）
- 所有 GND 用焊锡堆连成一片

焊完的**检查清单**（逐条做的）：

1. 万用表蜂鸣档逐点量通断
2. 放大镜检查排针密集处有没有锡桥
3. 轻拽每根线看会不会掉
4. 空载上电量 5V 是否为 5.0 ± 0.2V

### 2026-10-12 · 电压检测分压与低电压报警

分压电路 20kΩ + 10kΩ（比值 3.0），满电 8.4V 时 PB1 上是 2.8V < 3.3V 安全。
`config.h` 的 `VBAT_ADC_DIV = 3.0` 对应这个比值。

报警阈值定在 **6.60V**。两节 18650 串联的安全放电下限一般是 6.0V（单节 3.0V），
6.6V 留了余量，响的时候就该换电池了。

---

## 本板块关键数值

| 项目 | 实测值 | 备注 |
|---|---|---|
| 电池满电（2S 18650） | 8.4V | |
| 电池标称 | 7.4V | 规则上限即此值 |
| MG995 堵转电流 | ≈ 1.2A | 钳形表实测 |
| SG90 工作电流 | ≈ 0.2A（动）/ 0.01A（静） | |
| 四舵机同时动的总峰值 | ≈ 1.8A | 这是 5V 塌陷的根源 |
| 5V 实测（加电容+粗线后） | 4.95 ~ 5.05V | 舵机动作时最低 4.75V |
| 低电压报警阈值 | 6.60V | |

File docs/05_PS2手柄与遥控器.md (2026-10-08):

# PS2 手柄遥控与通信

## 功能描述

用组委会提供的 PS2 无线手柄（可对频锁定款）控制机器人，
并且**手柄掉线时车必须停下来** —— 这是安全要求，不是可选项。

代码：`firmware/Core/Src/ps2.c`，协议参数见 `config.h` 第 5 节。

---

### 2026-09-20 · SPI 配置：为什么是 CPOL=High / CPHA=2Edge

PS2 手柄的 SPI 时序是**空闲时钟为高、在第二个边沿采样**（SPI 模式 3）。
CubeMX 里对应：

```
SPI1: Full-Duplex Master, Software NSS
      CPOL = High
      CPHA = 2 Edge
      MSB First, 8 bits
      Baud Prescaler = 256   (72MHz / 256 ≈ 281kHz)
```

**波特率为什么选 256 而不是更快**：PS2 协议本身上限大概 500kHz，
但便宜手柄/接收器在 500kHz 下会偶发丢帧。281kHz 稳得多，
而我们一帧轮询只要 9 字节 × 8 bit / 281kHz ≈ 0.26ms，
5ms 控制周期里占 5%，完全够用。**宁可慢，不要偶发掉线。**

### 2026-09-27 · DI / DO 接反：调了三个小时的问题

**现象**：串口一直没有任何按键数据，`mode` 一直是 0。

**排查过程**（按顺序）：

1. 量接收器 VCC —— 3.3V 正常
2. 换了一个手柄 —— 还是不行
3. 怀疑 SPI 时序 —— 把 CPOL/CPHA 四种组合都试了一遍 —— 还是不行
4. 用示波器看 SCK 和 MISO —— **SCK 有波形，MISO 一直高**

第 4 步暴露了真相：**我们的 MISO 接到了手柄的 DI（数据输入）脚上**。

PS2 接收器的丝印是站在**手柄**的角度命名的：

| 模块丝印 | 含义 | 接 STM32 的 |
|---|---|---|
| DI | Data **In**（进手柄） | MOSI（PA7） |
| DO | Data **Out**（出手柄） | MISO（PA6） |

我们是站在 MCU 角度接的，正好反了。

**记下来的排查口诀**（写进了代码注释）：
> PS2 一直连不上，先把 PA6 / PA7 对调。**90% 的 PS2 调不通都是这两根线反了。**

### 2026-09-27 · 进模拟量模式：不然摇杆只有 0 和 255

手柄上电默认是**数字模式**，摇杆只回 0x00 / 0xFF 两档，没法做速度控制。

必须在初始化时进配置模式打开模拟量：

```c
enter_cfg :  01 43 00 01 00
set_mode  :  01 44 00 01 03 00 00 00 00    // 0x01 = 开模拟量
set_rumble:  01 4D 00 00 01 FF FF FF FF    // 关震动（省电 + 防接插件松）
exit_cfg  :  01 43 00 00 5A 5A 5A 5A 5A
```

**成功的标志**：手柄上的 MODE 灯**红灯常亮**（数字模式是不亮或另一种状态）。
串口打印的 `mode` 字节应该是 `0x73`（模拟绿灯）或 `0x79`（模拟红灯），
不应该是 `0x41`。

**注意**：进配置模式之前要先短轮询 3 次让手柄"醒"过来，
每条配置命令之间要有延时。我们第一版因为没加延时，配置命令全被吞了。

### 2026-09-27 · 字节间延时：便宜手柄必须要

在 `ps2_xfer()` 里每发一个字节后加了约 15μs 的延时（用 `__NOP()` 循环实现，
72MHz 下大约 9 个循环 = 1μs）。不加的话接收器跟不上，表现为偶发掉帧。

不能用 `HAL_Delay(1)`：一帧 9 个字节就是 9ms，而我们的控制周期才 5ms，会直接卡死调度。

### 2026-09-28 · 掉线保护：车绝不能"保持上一个指令继续跑"

这是安全设计，**不是可选优化**：

```c
if (!PS2_Poll()) {
    lost_cnt++;
    if (lost_cnt > PS2_LOST_THRESHOLD) {   // 25 次 ≈ 125ms
        connected = 0;
        btn = 0;
        lx = ly = rx = ry = 0;             // 关键：清掉残留摇杆量
    }
}
```

在 `app.c` 里：

```c
if (!ps2.connected) { vx = vy = wz = 0.0f; }
```

**为什么必须显式清零**：如果只做"不再更新指令"，
`g_cur` 里会保留掉线前最后一次的速度，车会**一直以那个速度跑下去**，
直到撞墙或撞人。这在 2400×2400 的对抗场里是实打实的危险。

LED 指示也接上了：手柄失联时 LED 从 1Hz 慢闪变成**常亮**，
操作手在场上不用看串口就知道发生了什么。

### 2026-09-28 · 摇杆映射：死区 + expo 曲线

| 问题 | 解法 |
|---|---|
| 摇杆回中不一定是精确的 128 | `PS2_STICK_DEADZONE = 12`，中间 ±12 当 0 |
| 去掉死区后低速有跳变 | 去掉死区后重新归一化到 0~1，再套 expo |
| 低速时太灵敏，难做精细对位 | `PS2_STICK_EXPO = 1.4`，指数曲线让中段更细腻 |

```c
a = (|x| - dz) / (1 - dz);     // 去掉死区并重新归一化
return sign(x) * powf(a, EXPO); // expo > 1 => 低速更细腻
```

### 2026-10-07 · 按键映射定稿

| 键 | 功能 | 为什么放这里 |
|---|---|---|
| 左摇杆 | 前后 + 左右平移 | 麦轮全向，直觉 |
| 右摇杆 X | 自转 | 和左摇杆分开，避免误触 |
| ○ | 宏1 地面自动收集 | 最常用的动作，放在最顺手的键 |
| △ | 宏2 挑物资架黄块 | |
| □ | 宏3 洞窟探杆 | |
| × | 宏4 一键贴边 | |
| L2 | 宏5 视觉对位（进阶） | 没开视觉时 L2 复用为前铲微调 |
| L1 | 全部机构收起（检录姿态） | 每局开始前必须按一次 |
| R1 | 前铲放下/抬起切换 | |
| SELECT | 手动 / 半自动切换 | |
| START | 急停（再按解除） | |
| ↑↓ / ←→ | 大臂 / 夹爪 ±2°（标定用） | **在线标定，见下** |

**在线标定是这套按键设计里最实用的一条**：
用方向键微调舵机角度，串口会实时打印当前角度，
调到满意的角度后直接把数字抄进 `config.h`。

比起"改宏 → 编译 → 下载 → 看效果"的循环（每次至少 1 分钟），
在线标定把一次迭代压到几秒钟。**舵机角度这种必须靠眼睛调的参数，
没有这个工具几乎没法调。**

### 2026-10-08 · 宏运行期间的人工接管

**设计**：宏运行期间，只要操作手动了摇杆（三轴绝对值之和 > 0.35），
立刻中止宏、交还控制权。

```c
if (Auto_Running()) {
    float mv = |stick(ly)| + |stick(lx)| + |stick(rx)|;
    if (mv > 0.35f) { Auto_Abort(); }
}
```

理由很简单：宏是**基于时间参数的盲走**，一旦现场情况和我们标定时不一样
（方块被对手推走了、地面脏了打滑了），继续跑下去只会把车顶在墙上。
让操作手随时能接管，是这个宏敢上场的唯一原因。

---

## 本板块参数

| 宏 | 值 | 备注 |
|---|---|---|
| `PS2_STICK_DEADZONE` | 12 | 手柄个体差异大，可到 20 |
| `PS2_LOST_THRESHOLD` | 25 | ≈ 125ms，再长就有安全风险 |
| `PS2_STICK_EXPO` | 1.4 | 1.0 = 线性 |
| SPI 预分频 | 256 | ≈ 281kHz |
| 字节间延时 | 15μs | 便宜手柄必加 |

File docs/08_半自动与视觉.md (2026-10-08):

# 半自动与视觉

## 功能描述

让操作手**按一个键**就能完成"对中 → 夹紧 → 抬起 → 入仓"，
从而争取手册里的**半自动得分倍率**（能量单元 ×1.5、能量核心 ×1.25）。
视觉（K210）作为**进阶功能**独立评估，不进主链路 —— 视觉挂了车还能打。

代码：`auto_task.c`（宏状态机）、`sensor.c`（对中检测）、`vision.c` + `vision/k210_find_cube.py`。

---

### 2026-09-17 · 先说清楚：半自动不是强制项

我们逐条核对了手册 4.1 的基础功能清单，**没有**"必须完成半自动"这一条。
手册里关于自动/半自动的内容只有两处：

1. 定义（3.3.1）：全自动 = 无需操作手 + 经组委会审查确定；只满足一部分 = 半自动
2. 得分倍率（4.2）：全自动 能量单元 ×2 / 核心 ×1.5；半自动 ×1.5 / ×1.25

所以半自动是**加分手段**而不是及格线。我们仍然要做，因为 1.5 倍是白给的，
但要把它做成"**稳**的半自动"而不是"炫的半自动"。

### 2026-09-26 · 技术选型：机械对中 vs 视觉识别

| 方案 | 原理 | 优点 | 缺点 | 成本 |
|---|---|---|---|---|
| **机械对中（微动开关）** | V 型喇叭口两侧各一个摆杆，方块同时压到两者 = 已居中 | 不受光照影响、不需要调阈值、响应 < 30ms、新手半小时能调通 | 只能对正前方约 ±20° 的方块 | ¥5 |
| 视觉识别（K210/OpenMV） | 色块识别 → 串口发坐标 → P 控制转向对位 | 能主动搜索、距离远也能对 | 受光照影响大、阈值要现场抠、需要额外 UART + 供电、新手调试周期长 | ¥60~90 |

**决策：机械对中做主方案，视觉做进阶功能。**

理由：

1. 我们的核心诉求是"**稳定拿到半自动倍率**"，不是"炫技"。
   机械对中的失败模式是"没对准"（车停下来，操作手再试一次），
   视觉的失败模式是"对到了错误的目标"（车冲向错误方向，可能撞墙）。
2. 成本：视觉模块 60~90 元会让我们**超过 400 元的推荐成本线**。
3. 时间：中期考核前只有 3 周，视觉的阈值标定 + 串口联调 + 控制参数整定
   至少占用 1 周，会挤压底盘和机构的调试时间。

**但视觉代码我们照样写了**（`vision/` 目录 + `config.h` 的 `USE_VISION` 开关），
因为它是很好的**进阶功能**素材（最多 3 项、最高 +9 分），
而且中期考核后如果晋级，有预算再买也不迟。

### 2026-10-05 · 对中检测：两个微动开关 + 时间窗口

硬件：V 型喇叭口两侧各装一个 KW11 微动开关，带 45mm 长的摆杆
（`06_limit_lever.stl`），摆杆被方块压向内侧时开关闭合。

判定逻辑（`sensor.c`）：

```c
// 判定"已对中"：左右两个开关都被压过，且两次压下时刻相差 < 400ms
uint8_t Limit_Centered(uint32_t now) {
    if (!l_stable || !r_stable) return 0;
    if (now - l_hit_ms > LIMIT_BOTH_WINDOW_MS) return 0;
    if (now - r_hit_ms > LIMIT_BOTH_WINDOW_MS) return 0;
    int32_t diff = l_hit_ms - r_hit_ms;
    return (|diff| <= LIMIT_BOTH_WINDOW_MS) ? 1 : 0;
}
```

**为什么要"时间窗口"而不是"同时闭合"**：

方块进喇叭口时几乎不可能**精确同时**压到左右两个摆杆 ——
总会有一侧先被碰到。如果要求"同时闭合"，实际永远触发不了。
用 400ms 的窗口，允许先后差 400ms 以内都算对中，鲁棒性立刻上来。

**为什么还要"两个都闭合"**：
只压到一个说明方块是斜着进来的（撞在喇叭口一侧），这时候夹紧会夹空。

去抖 30ms（微动开关机械抖动典型值 5~20ms）。

### 2026-10-07 · 一键宏 v1

状态机（`auto_task.c`）：

```
step 0: Arm_Start(POSE_READY)        前铲放下、夹爪张开
step 1: 等机构到位（>2s 判失败）
step 2: 以 0.35 慢速前进，等 Limit_Centered() 触发
        └─ 触发 -> step 3；超时 2500ms -> 判失败，机构收起
step 3: Arm_Start(POSE_PICK_GROUND)  夹紧 -> 抬起 -> 兜入仓
step 4: 等机构跑完（>3s 判失败）
step 5: 后退 300ms @ 0.30，确认方块在车上 -> 成功
```

**三条安全设计**（这是敢让它上场的原因）：

1. **每个 step 都有硬超时**，卡住不会一直顶着电机（顶着 = 堵转 = 烧驱动/电池）
2. **失败也要收机构**：`finish(0)` 里调 `Arm_Start(POSE_STOW)`，
   绝不张着爪子到处跑
3. **操作手动摇杆立刻中止**

### 2026-10-07 · 为什么慢速靠拢是 0.35 而不是更快

实测对照（每档 10 次）【待回填：补表】：

| 靠拢速度 | 成功 | 失败模式 |
|---|---|---|
| 0.60 | 2/10 | 方块被撞飞出去 |
| 0.45 | 5/10 | 一半被撞飞，一半压不到限位 |
| **0.35** | **7/10** | 主要是斜撞后被弹到侧面 |
| 0.25 | 6/10 | 成功率高但太慢，5 分钟里拿不到几个 |

0.35 是"成功率 × 节奏"的折中。这个参数**必须在实车上重标**，
因为地胶的脏污程度、电池电量都会影响。

### 2026-10-13 · 视觉模块评估与成本决策

如果要上视觉，我们评估过的方案：

| 模块 | 价格 | 优点 | 缺点 |
|---|---|---|---|
| K210（Maix Bit / Dock） | ¥60~90 | 有硬件 KPU，能跑色块/分类，MaixPy 好上手 | 需要额外 5V 供电，体积不小（约 55×30mm） |
| OpenMV | ¥200+ | 生态最好 | 远超预算，且规则允许但成本线不允许 |
| ESP32-CAM | ¥25 | 最便宜 | 算力弱、没有好用的图像处理库、帧率低 |

**结论**：如果做，选 **K210**，但排在中期考核之后。
成本上：官方物资表 353.48 + 必买件 62 + K210 90 ≈ 505 元，
超过推荐线 400 元约 25%。

我们的处理办法是**先不买**，把视觉作为"如果晋级再加"的储备，
并在文档里如实说明。成本规范对新生组的措辞是"**不推荐超过**"而非"不得超过"，
但既然是"不推荐"，能不超就不超。

### 2026-10-13 · 视觉协议：定长帧 + 异或校验

K210 → STM32 的帧（14 字节）：

```
AA 55 cls xL xH yL yH wL wH hL hH areaL areaH chk
```

- `cls`：1 = 白块、2 = 黄块、0 = 没找到
- `x / y`：目标中心像素坐标（画面 320×240，中心 160,120）
- `w / h / area`：色块尺寸与面积（面积用于判断"已经够近了"）
- `chk`：从 cls 到 areaH 全部字节异或，低 8 位

**为什么不用 `\r\n` 做帧尾**：`0x0D` 和 `0x0A` 都可能出现在数据里，
状态机会被带跑，出现"数据错位但还在收"的怪事 —— 这种 bug 新手能查一整天。
定长帧 + 校验和没有这个问题。

**为什么面积比距离更重要**：我们不做测距（标定太麻烦），
直接用色块像素面积判断是否到位（`VISION_NEAR_AREA = 9000`）。
近了面积就大，够了就夹。这是个"够用就行"的简化，
在 V1.3 的 40mm 方块场景下工作得很好（V1.4 改成 30mm，尺寸阈值要按 30mm 重测）。
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

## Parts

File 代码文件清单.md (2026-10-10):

# 代码文件清单

打包文件：`D:\WorkBuddy\CRTC交付\CRTC_代码包_只有代码.zip`
共 68 个文件

## 最重要 / 最常用的文件

- `firmware/Core/Src/main.c` —— 主程序：上电初始化 + 主循环
- `firmware/Core/Src/mecanum.c` —— 麦轮运动解算（横移/斜走/自转的数学）
- `firmware/Core/Src/motor.c` —— 电机输出层（PWM + 方向 + 死区补偿）
- `firmware/Core/Src/ps2.c` —— PS2 手柄通信（SPI 读写 + 按键解析）
- `firmware/Core/Src/servo.c` —— 舵机控制（角度插值 + 姿态）
- `firmware/Core/Src/arm.c` —— 机械臂动作序列（取块/举升/入仓）
- `firmware/Core/Src/auto_task.c` —— 半自动宏（一键收集/挑架/探洞/贴边）
- `firmware/Core/Src/auto_full.c` —— 全自动调度器（在半自动宏之上）
- `firmware/Core/Src/bsp.c` —— 外设初始化（时钟/GPIO/定时器/SPI/串口）
- `firmware/Core/Src/sensor.c` —— 限位开关 + 电池电压检测
- `firmware/Core/Src/vision.c` —— 视觉模块串口协议解析（可选）
- `firmware/Core/Src/hal_shim.c` —— ★ 自写的 HAL 替代层（官方 HAL 下载不到）
- `firmware/Core/Src/startup_stm32f103xb.c` —— 启动文件（C 写的，不调 .init_array）
- `firmware/Core/Src/test_motion.c` —— 测试固件：只测底盘跑动
- `firmware/Core/Src/test_arm.c` —— 测试固件：只测舵机/机械臂
- `firmware/Core/Src/test_vision.c` —— 测试固件：只测摄像头
- `firmware/Core/Inc/config.h` —— ★★ 全车唯一调参入口（95% 的时间只改这个）
- `firmware/Core/Inc/board.h` —— 硬件引脚映射表（改接线前先看这个）
- `tools/build.py` —— 编译固件（替代 make）
- `tools/flash.py` —— 一键烧录（自动找 CubeIDE 的烧录器）
- `tools/check_symbols.py` —— 静态自检（查符号/宏缺失）
- `tools/print_bill.py` —— 打印清单与重量估算
- `tools/slice_k1.py` —— 自研切片器（STL → K1 Max 的 G-code）
- `tools/check_gcode.py` —— G-code 六项自检

## 完整清单

- `README.md`
- `cpp/README.md`
- `cpp/inc/crtc.hpp`
- `cpp/main_mcu.cpp`
- `cpp/main_sim.cpp`
- `cpp/src/arm.cpp`
- `cpp/src/chassis.cpp`
- `cpp/src/hal_mcu.cpp`
- `cpp/src/hal_sim.cpp`
- `cpp/src/motor.cpp`
- `cpp/src/params.cpp`
- `cpp/src/servo.cpp`
- `cpp/src/vision.cpp`
- `firmware/Core/Inc/app.h`
- `firmware/Core/Inc/arm.h`
- `firmware/Core/Inc/auto_full.h`
- `firmware/Core/Inc/auto_task.h`
- `firmware/Core/Inc/board.h`
- `firmware/Core/Inc/bsp.h`
- `firmware/Core/Inc/chassis_diff.h`
- `firmware/Core/Inc/config.h`
- `firmware/Core/Inc/hal_shim.h`
- `firmware/Core/Inc/main.h`
- `firmware/Core/Inc/mecanum.h`
- `firmware/Core/Inc/motor.h`
- `firmware/Core/Inc/ps2.h`
- `firmware/Core/Inc/sensor.h`
- `firmware/Core/Inc/servo.h`
- `firmware/Core/Inc/stm32f103_regs.h`
- `firmware/Core/Inc/vision.h`
- `firmware/Core/Src/app.c`
- `firmware/Core/Src/arm.c`
- `firmware/Core/Src/auto_full.c`
- `firmware/Core/Src/auto_task.c`
- `firmware/Core/Src/bsp.c`
- `firmware/Core/Src/chassis_diff.c`
- `firmware/Core/Src/hal_shim.c`
- `firmware/Core/Src/main.c`
- `firmware/Core/Src/mecanum.c`
- `firmware/Core/Src/motor.c`
- `firmware/Core/Src/ps2.c`
- `firmware/Core/Src/sensor.c`
- `firmware/Core/Src/servo.c`
- `firmware/Core/Src/startup_stm32f103xb.c`
- `firmware/Core/Src/syscalls.c`
- `firmware/Core/Src/test_arm.c`
- `firmware/Core/Src/test_motion.c`
- `firmware/Core/Src/test_ps2.c`
- `firmware/Core/Src/test_vision.c`
- `firmware/Core/Src/vision.c`
- `firmware/STM32F103C8TX_FLASH.ld`
- `firmware/构建烧录与测试.md`
- `firmware/烧录接口与ST-LINK说明.md`
- `firmware/编译与烧录指南.md`
- `tools/build.py`
- `tools/build_cpp.py`
- `tools/check_arm_clearance.py`
- `tools/check_gcode.py`
- `tools/check_symbols.py`
- `tools/flash.py`
- `tools/gen_step.py`
- `tools/pack_code.py`
- `tools/print_bill.py`
- `tools/render_asm.py`
- `tools/render_wheel_note.py`
- `tools/repack_zips.py`
- `tools/slice_k1.py`
- `vision/k210_find_cube.py`

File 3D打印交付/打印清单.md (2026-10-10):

# 3D 打印清单（自动生成）

> 由 `tools/print_bill.py` 扫描 `mechanical/stl` 与 `mechanical/stl_pretty` 生成，
> 名称 / 数量 / 批次直接从 `gen_parts.py`、`gen_shell.py` 抓取，不会和图纸集对不上。
> 重量按 PLA 密度 1.24 g/cm³ × 用料系数 0.45 估算，**打完请实称**。

共 **55 个文件 / 71 件**，实体总体积 713598 mm³，估算总重 **398 g**。

## 按批次

| 批次 | 文件数 | 件数 | 估算重量 | 什么时候打 |
|---|---|---|---|---|
| ① 底盘必打 | 8 | 12 | 117 g | 现在就打，装完车能跑 |
| ② 收集与储仓 | 9 | 13 | 80 g | 底盘装好就打 |
| ③ 机械臂与机构 | 14 | 15 | 84 g | 车能跑之后 |
| ④ 外观套件（最后打） | 14 | 14 | 72 g | 最后打，不影响功能 |
| 其他 | 10 | 17 | 46 g |  |

## 结构件（41 个文件 / 57 件，约 326 g）

| 文件 | 名称 | 数量 | 尺寸 X×Y×Z (mm) | 单件重 | 层高 | 填充 | 支撑 |
|---|---|---|---|---|---|---|---|
| `01_deck_front.stl` | 前段主甲板 | ×1 | 128 × 162 × 4 | 36.2 g | 0.20 | 30% | Brim 8mm |
| `02_deck_rear.stl` | 后段主甲板 | ×1 | 128 × 162 × 4 | 38.3 g | 0.20 | 30% | Brim 8mm |
| `03_deck_splice.stl` | 甲板搭接板 | ×1 | 60 × 60 × 3 | 5.9 g | 0.20 | 30% | 否 |
| `04_column.stl` | 甲板立柱 | ×4 | 12 × 12 × 22 | 1.3 g | 0.20 | 30% | 否 |
| `18_electronics_tray.stl` | 电控托盘 | ×1 | 110 × 80 × 3 | 12.7 g | 0.20 | 30% | 否 |
| `19_battery_clip.stl` | 18650 电池盒卡箍 | ×1 | 54 × 52 × 3 | 1.9 g | 0.20 | 30% | 否 |
| `20_bumper_front.stl` | 前保险杠 | ×1 | 16 × 108 × 10 | 7.4 g | 0.20 | 30% | 否 |
| `21_anti_tip.stl` | 防翻侧杆 | ×2 | 116 × 16 × 5 | 4.6 g | 0.20 | 30% | 否 |
| `05_scoop_floor.stl` | 收集铲底板（V 型） | ×1 | 28 × 96 × 6 | 6.5 g | 0.20 | 30% | 否 |
| `05b_scoop_wall_L.stl` | 收集铲侧板（左） | ×1 | 28 × 29 × 26 | 2.3 g | 0.20 | 30% | 否 |
| `05c_scoop_wall_R.stl` | 收集铲侧板（右） | ×1 | 28 × 29 × 26 | 2.3 g | 0.20 | 30% | 否 |
| `05d_scoop_back.stl` | 收集铲后壁（对中挡板） | ×1 | 8 × 64 × 26 | 7.2 g | 0.20 | 30% | 否 |
| `12_bin_floor.stl` | 储仓底板 | ×1 | 100 × 136 × 3 | 22.0 g | 0.20 | 30% | Brim 8mm |
| `13_bin_side.stl` | 储仓侧板 | ×2 | 100 × 52 × 3 | 8.1 g | 0.20 | 30% | 否 |
| `14_bin_divider.stl` | 储仓隔板 | ×2 | 130 × 46 × 3 | 7.6 g | 0.20 | 30% | Brim 8mm |
| `15_bin_flap.stl` | 储仓单向挡板 | ×3 | 42 × 30 × 2 | 1.3 g | 0.20 | 40% | 否 |
| `22_ramp_anchor.stl` | 坡道防滑撑地块 | ×1 | 48 × 24 × 8 | 4.7 g | 0.20 | 30% | 否 |
| `06_limit_lever.stl` | 对中限位摆杆 | ×2 | 45 × 12 × 4 | 1.2 g | 0.20 | 30% | 否 |
| `07_grip_finger_L.stl` | 夹爪指（左） | ×1 | 46 × 16 × 6 | 1.7 g | 0.20 | 30% | 否 |
| `08_grip_finger_R.stl` | 夹爪指（右） | ×1 | 46 × 16 × 6 | 1.7 g | 0.20 | 30% | 否 |
| `16_rack_hook.stl` | 物资架挑杆头 | ×1 | 70 × 24 × 6 | 3.5 g | 0.20 | 30% | 否 |
| `17_cave_probe.stl` | 洞窟探杆头 | ×1 | 92 × 20 × 6 | 3.8 g | 0.20 | 30% | 否 |
| `23_cam_mast.stl` | 视觉模块支架 | ×1 | 118 × 36 × 4 | 8.2 g | 0.20 | 30% | 否 |
| `30_arm_base.stl` | 机械臂·回转底座（柱坐标） | ×1 | 64 × 44 × 40 | 15.2 g | 0.20 | 30% | 否 |
| `31a_arm_turntable.stl` | 机械臂·回转盘（柱坐标） | ×1 | 64 × 44 × 6 | 6.9 g | 0.20 | 30% | 否 |
| `31b_arm_mast.stl` | 机械臂·立柱（柱坐标） | ×1 | 40 × 40 × 63 | 15.5 g | 0.20 | 30% | 否 |
| `32_arm_carriage.stl` | 机械臂·滑座（柱坐标） | ×1 | 52 × 52 × 32 | 10.9 g | 0.20 | 30% | 否 |
| `33_arm_boom.stl` | 机械臂·爪横臂（柱坐标） | ×1 | 38 × 24 × 8 | 4.0 g | 0.20 | 30% | 否 |
| `34_arm_lift_crank.stl` | 机械臂·升降曲柄（柱坐标） | ×1 | 18 × 28 × 8 | 1.4 g | 0.20 | 30% | 否 |
| `35_arm_lift_link.stl` | 机械臂·升降连杆（柱坐标） | ×1 | 56 × 8 × 6 | 1.2 g | 0.20 | 30% | 否 |
| `36_arm_lift_cap.stl` | 机械臂·顶帽（柱坐标） | ×1 | 60 × 60 × 6 | 7.1 g | 0.20 | 30% | 否 |
| `24a_claw_base.stl` | 平行夹爪·爪架底板 | ×1 | 74 × 56 × 4 | 4.6 g | 0.20 | 30% | 否 |
| `24b_claw_slider.stl` | 平行夹爪·滑块 | ×2 | 18 × 16 × 12 | 1.8 g | 0.20 | 30% | 否 |
| `24c_claw_finger.stl` | 平行夹爪·爪指 | ×2 | 6 × 26 × 34 | 2.7 g | 0.20 | 30% | 否 |
| `24d_claw_horn.stl` | 平行夹爪·舵机摇臂 | ×1 | 33 × 6 × 3 | 0.3 g | 0.20 | 30% | 否 |
| `24e_claw_link.stl` | 平行夹爪·连杆 | ×2 | 34 × 6 × 3 | 0.3 g | 0.20 | 30% | 否 |
| `24f_claw_gear.stl` | 齿轮夹爪·齿轮 | ×2 | 15 × 15 × 6 | 0.3 g | 0.20 | 30% | 否 |
| `24g_claw_rack.stl` | 齿轮夹爪·齿条滑块 | ×2 | 44 × 15 × 12 | 3.8 g | 0.20 | 30% | 否 |
| `24h_claw_base_gear.stl` | 齿轮夹爪·爪架底板 | ×1 | 74 × 56 × 4 | 3.8 g | 0.20 | 30% | 否 |
| `24i_claw_finger_gear.stl` | 齿轮夹爪·爪指 | ×3 | 6 × 36 × 34 | 3.9 g | 0.20 | 30% | 否 |
| `26_cube_mock.stl` | 26_cube_mock | ×1 | 30 × 30 × 30 | 7.4 g | 0.20 | 30% | 否 |

## 外观件（14 个文件 / 14 件，约 72 g）

| 文件 | 名称 | 数量 | 尺寸 X×Y×Z (mm) | 单件重 | 层高 | 填充 | 支撑 |
|---|---|---|---|---|---|---|---|
| `P1_nose_shell.stl` | 前脸罩（U 形，带喇叭口） | ×1 | 60 × 168 × 46 | 6.7 g | 0.16 | 15% | 否 |
| `P2_skirt_L1.stl` | P2_skirt_L1 | ×1 | 150 × 2 × 34 | 4.8 g | 0.16 | 15% | 否 |
| `P2_skirt_L2.stl` | P2_skirt_L2 | ×1 | 150 × 2 × 34 | 4.8 g | 0.16 | 15% | 否 |
| `P2_skirt_R1.stl` | P2_skirt_R1 | ×1 | 150 × 2 × 34 | 4.8 g | 0.16 | 15% | 否 |
| `P2_skirt_R2.stl` | P2_skirt_R2 | ×1 | 150 × 2 × 34 | 4.8 g | 0.16 | 15% | 否 |
| `P3_top_cover.stl` | 顶部盖板（减重孔 + 铭牌区） | ×1 | 150 × 120 × 2 | 20.7 g | 0.16 | 15% | 否 |
| `P4_fender_1.stl` | P4_fender_1 | ×1 | 68 × 26 × 34 | 4.4 g | 0.16 | 15% | 否 |
| `P4_fender_2.stl` | P4_fender_2 | ×1 | 68 × 26 × 34 | 4.4 g | 0.16 | 15% | 否 |
| `P4_fender_3.stl` | P4_fender_3 | ×1 | 68 × 26 × 34 | 4.4 g | 0.16 | 15% | 否 |
| `P4_fender_4.stl` | P4_fender_4 | ×1 | 68 × 26 × 34 | 4.4 g | 0.16 | 15% | 否 |
| `P5a_tail_plate.stl` | 尾部横板 | ×1 | 120 × 16 × 3 | 2.7 g | 0.16 | 15% | 否 |
| `P5b_tail_arm_L.stl` | P5b_tail_arm_L | ×1 | 34 × 32 × 3 | 1.5 g | 0.16 | 15% | 否 |
| `P5b_tail_arm_R.stl` | P5b_tail_arm_R | ×1 | 34 × 32 × 3 | 1.5 g | 0.16 | 15% | 否 |
| `P6_number_plate.stl` | 编号牌（空白，贴字母） | ×1 | 64 × 32 × 2 | 2.3 g | 0.16 | 15% | 否 |

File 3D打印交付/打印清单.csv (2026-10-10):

批次 | 文件 | 中文名 | 数量 | 建议多打一份 | 尺寸X | 尺寸Y | 尺寸Z | 实体体积mm3 | 单件重g | 小计g | 层高mm | 填充% | 支撑 | 备注
① 底盘必打 | 01_deck_front.stl | 前段主甲板 | 1 |  | 128.0 | 162.0 | 4.0 | 64794 | 36.2 | 36.2 | 0.20 | 30% | Brim 8mm | 薄板件，切片时基本会被外壳填满；大面积要防翘边
① 底盘必打 | 02_deck_rear.stl | 后段主甲板 | 1 |  | 128.0 | 162.0 | 4.0 | 68646 | 38.3 | 38.3 | 0.20 | 30% | Brim 8mm | 薄板件，切片时基本会被外壳填满；大面积要防翘边
① 底盘必打 | 03_deck_splice.stl | 甲板搭接板 | 1 |  | 60.0 | 60.0 | 3.0 | 10655 | 5.9 | 5.9 | 0.20 | 30% | 否 | 薄板件，切片时基本会被外壳填满；大面积要防翘边
① 底盘必打 | 04_column.stl | 甲板立柱 | 4 |  | 12.0 | 12.0 | 22.0 | 2307 | 1.3 | 5.2 | 0.20 | 30% | 否 | 结构件受力，填充别低于 25%
① 底盘必打 | 18_electronics_tray.stl | 电控托盘 | 1 |  | 110.0 | 80.0 | 3.0 | 22753 | 12.7 | 12.7 | 0.20 | 30% | 否 | 薄板件，切片时基本会被外壳填满；大面积要防翘边
① 底盘必打 | 19_battery_clip.stl | 18650 电池盒卡箍 | 1 |  | 54.0 | 52.0 | 3.0 | 3459 | 1.9 | 1.9 | 0.20 | 30% | 否 | 薄板件，切片时基本会被外壳填满；大面积要防翘边
① 底盘必打 | 20_bumper_front.stl | 前保险杠 | 1 |  | 16.0 | 108.0 | 10.0 | 13233 | 7.4 | 7.4 | 0.20 | 30% | 否 | 结构件受力，填充别低于 25%
① 底盘必打 | 21_anti_tip.stl | 防翻侧杆 | 2 |  | 116.0 | 16.0 | 5.0 | 8197 | 4.6 | 9.1 | 0.20 | 30% | 否 | 结构件受力，填充别低于 25%
② 收集与储仓 | 05_scoop_floor.stl | 收集铲底板（V 型） | 1 |  | 28.0 | 96.0 | 6.0 | 11733 | 6.5 | 6.5 | 0.20 | 30% | 否 | 结构件受力，填充别低于 25%
② 收集与储仓 | 05b_scoop_wall_L.stl | 收集铲侧板（左） | 1 |  | 28.0 | 29.0 | 26.0 | 4092 | 2.3 | 2.3 | 0.20 | 30% | 否 | 结构件受力，填充别低于 25%
② 收集与储仓 | 05c_scoop_wall_R.stl | 收集铲侧板（右） | 1 |  | 28.0 | 29.0 | 26.0 | 4092 | 2.3 | 2.3 | 0.20 | 30% | 否 | 结构件受力，填充别低于 25%
② 收集与储仓 | 05d_scoop_back.stl | 收集铲后壁（对中挡板） | 1 |  | 8.0 | 64.0 | 26.0 | 12894 | 7.2 | 7.2 | 0.20 | 30% | 否 | 结构件受力，填充别低于 25%
② 收集与储仓 | 12_bin_floor.stl | 储仓底板 | 1 |  | 100.0 | 136.0 | 3.0 | 39349 | 22.0 | 22.0 | 0.20 | 30% | Brim 8mm | 薄板件，切片时基本会被外壳填满；大面积要防翘边
② 收集与储仓 | 13_bin_side.stl | 储仓侧板 | 2 |  | 100.0 | 52.0 | 3.0 | 14466 | 8.1 | 16.1 | 0.20 | 30% | 否 | 薄板件，切片时基本会被外壳填满；大面积要防翘边
② 收集与储仓 | 14_bin_divider.stl | 储仓隔板 | 2 |  | 130.0 | 46.0 | 3.0 | 13622 | 7.6 | 15.2 | 0.20 | 30% | Brim 8mm | 薄板件，切片时基本会被外壳填满；大面积要防翘边
② 收集与储仓 | 15_bin_flap.stl | 储仓单向挡板 | 3 |  | 42.0 | 30.0 | 2.0 | 2398 | 1.3 | 4.0 | 0.20 | 40% | 否 | 超薄件（≤2.5mm），填充给满才不容易掰断
② 收集与储仓 | 22_ramp_anchor.stl | 坡道防滑撑地块 | 1 |  | 48.0 | 24.0 | 8.0 | 8350 | 4.7 | 4.7 | 0.20 | 30% | 否 | 结构件受力，填充别低于 25%
③ 机械臂与机构 | 06_limit_lever.stl | 对中限位摆杆 | 2 |  | 45.0 | 12.0 | 4.0 | 2118 | 1.2 | 2.4 | 0.20 | 30% | 否 | 薄板件，切片时基本会被外壳填满；大面积要防翘边
③ 机械臂与机构 | 07_grip_finger_L.stl | 夹爪指（左） | 1 |  | 46.5 | 16.5 | 6.0 | 3037 | 1.7 | 1.7 | 0.20 | 30% | 否 | 结构件受力，填充别低于 25%
③ 机械臂与机构 | 08_grip_finger_R.stl | 夹爪指（右） | 1 |  | 46.5 | 16.5 | 6.0 | 3037 | 1.7 | 1.7 | 0.20 | 30% | 否 | 结构件受力，填充别低于 25%
③ 机械臂与机构 | 16_rack_hook.stl | 物资架挑杆头 | 1 |  | 70.0 | 24.0 | 6.0 | 6203 | 3.5 | 3.5 | 0.20 | 30% | 否 | 结构件受力，填充别低于 25%
③ 机械臂与机构 | 17_cave_probe.stl | 洞窟探杆头 | 1 |  | 92.0 | 20.0 | 6.0 | 6791 | 3.8 | 3.8 | 0.20 | 30% | 否 | 结构件受力，填充别低于 25%
③ 机械臂与机构 | 23_cam_mast.stl | 视觉模块支架 | 1 |  | 118.0 | 36.0 | 4.0 | 14678 | 8.2 | 8.2 | 0.20 | 30% | 否 | 薄板件，切片时基本会被外壳填满；大面积要防翘边
③ 机械臂与机构 | 30_arm_base.stl | 机械臂·回转底座（柱坐标） | 1 |  | 64.0 | 44.0 | 40.0 | 27200 | 15.2 | 15.2 | 0.20 | 30% | 否 | 结构件受力，填充别低于 25%
③ 机械臂与机构 | 31a_arm_turntable.stl | 机械臂·回转盘（柱坐标） | 1 |  | 64.0 | 44.0 | 6.0 | 12374 | 6.9 | 6.9 | 0.20 | 30% | 否 | 结构件受力，填充别低于 25%
③ 机械臂与机构 | 31b_arm_mast.stl | 机械臂·立柱（柱坐标） | 1 |  | 40.0 | 40.0 | 62.7 | 27817 | 15.5 | 15.5 | 0.20 | 30% | 否 | 结构件受力，填充别低于 25%
③ 机械臂与机构 | 32_arm_carriage.stl | 机械臂·滑座（柱坐标） | 1 |  | 52.0 | 52.0 | 32.0 | 19546 | 10.9 | 10.9 | 0.20 | 30% | 否 | 结构件受力，填充别低于 25%
③ 机械臂与机构 | 33_arm_boom.stl | 机械臂·爪横臂（柱坐标） | 1 |  | 38.0 | 24.0 | 8.0 | 7232 | 4.0 | 4.0 | 0.20 | 30% | 否 | 结构件受力，填充别低于 25%
③ 机械臂与机构 | 34_arm_lift_crank.stl | 机械臂·升降曲柄（柱坐标） | 1 |  | 18.0 | 27.9 | 8.0 | 2521 | 1.4 | 1.4 | 0.20 | 30% | 否 | 结构件受力，填充别低于 25%
③ 机械臂与机构 | 35_arm_lift_link.stl | 机械臂·升降连杆（柱坐标） | 1 |  | 56.0 | 8.0 | 6.0 | 2236 | 1.2 | 1.2 | 0.20 | 30% | 否 | 结构件受力，填充别低于 25%
③ 机械臂与机构 | 36_arm_lift_cap.stl | 机械臂·顶帽（柱坐标） | 1 |  | 60.0 | 60.0 | 6.0 | 12798 | 7.1 | 7.1 | 0.20 | 30% | 否 | 结构件受力，填充别低于 25%
④ 外观套件（最后打） | P1_nose_shell.stl | 前脸罩（U 形，带喇叭口） | 1 |  | 60.4 | 168.0 | 46.0 | 12021 | 6.7 | 6.7 | 0.16 | 15% | 否 | 外观件，层高小一点好看；不承重，15% 填充够用
④ 外观套件（最后打） | P2_skirt_L1.stl | P2_skirt_L1 | 1 |  | 150.0 | 2.5 | 34.0 | 8522 | 4.8 | 4.8 | 0.16 | 15% | 否 | 外观件，层高小一点好看；不承重，15% 填充够用
④ 外观套件（最后打） | P2_skirt_L2.stl | P2_skirt_L2 | 1 |  | 150.0 | 2.5 | 34.0 | 8522 | 4.8 | 4.8 | 0.16 | 15% | 否 | 外观件，层高小一点好看；不承重，15% 填充够用
④ 外观套件（最后打） | P2_skirt_R1.stl | P2_skirt_R1 | 1 |  | 150.0 | 2.5 | 34.0 | 8522 | 4.8 | 4.8 | 0.16 | 15% | 否 | 外观件，层高小一点好看；不承重，15% 填充够用
④ 外观套件（最后打） | P2_skirt_R2.stl | P2_skirt_R2 | 1 |  | 150.0 | 2.5 | 34.0 | 8522 | 4.8 | 4.8 | 0.16 | 15% | 否 | 外观件，层高小一点好看；不承重，15% 填充够用
④ 外观套件（最后打） | P3_top_cover.stl | 顶部盖板（减重孔 + 铭牌区） | 1 |  | 150.0 | 120.0 | 2.5 | 37073 | 20.7 | 20.7 | 0.16 | 15% | 否 | 外观件，层高小一点好看；不承重，15% 填充够用
④ 外观套件（最后打） | P4_fender_1.stl | P4_fender_1 | 1 |  | 68.0 | 26.0 | 34.0 | 7941 | 4.4 | 4.4 | 0.16 | 15% | 否 | 外观件，层高小一点好看；不承重，15% 填充够用
④ 外观套件（最后打） | P4_fender_2.stl | P4_fender_2 | 1 |  | 68.0 | 26.0 | 34.0 | 7941 | 4.4 | 4.4 | 0.16 | 15% | 否 | 外观件，层高小一点好看；不承重，15% 填充够用
④ 外观套件（最后打） | P4_fender_3.stl | P4_fender_3 | 1 |  | 68.0 | 26.0 | 34.0 | 7941 | 4.4 | 4.4 | 0.16 | 15% | 否 | 外观件，层高小一点好看；不承重，15% 填充够用
④ 外观套件（最后打） | P4_fender_4.stl | P4_fender_4 | 1 |  | 68.0 | 26.0 | 34.0 | 7941 | 4.4 | 4.4 | 0.16 | 15% | 否 | 外观件，层高小一点好看；不承重，15% 填充够用
④ 外观套件（最后打） | P5a_tail_plate.stl | 尾部横板 | 1 |  | 120.0 | 16.0 | 3.0 | 4809 | 2.7 | 2.7 | 0.16 | 15% | 否 | 外观件，层高小一点好看；不承重，15% 填充够用
④ 外观套件（最后打） | P5b_tail_arm_L.stl | P5b_tail_arm_L | 1 |  | 34.0 | 32.0 | 3.0 | 2604 | 1.5 | 1.5 | 0.16 | 15% | 否 | 外观件，层高小一点好看；不承重，15% 填充够用
④ 外观套件（最后打） | P5b_tail_arm_R.stl | P5b_tail_arm_R | 1 |  | 34.0 | 32.0 | 3.0 | 2604 | 1.5 | 1.5 | 0.16 | 15% | 否 | 外观件，层高小一点好看；不承重，15% 填充够用
④ 外观套件（最后打） | P6_number_plate.stl | 编号牌（空白，贴字母） | 1 |  | 64.0 | 32.0 | 2.0 | 4047 | 2.3 | 2.3 | 0.16 | 15% | 否 | 外观件，层高小一点好看；不承重，15% 填充够用
其他 | 24a_claw_base.stl | 平行夹爪·爪架底板 | 1 |  | 74.0 | 56.0 | 4.0 | 8319 | 4.6 | 4.6 | 0.20 | 30% | 否 | 薄板件，切片时基本会被外壳填满；大面积要防翘边
其他 | 24b_claw_slider.stl | 平行夹爪·滑块 | 2 |  | 18.0 | 16.0 | 12.0 | 3210 | 1.8 | 3.6 | 0.20 | 30% | 否 | 结构件受力，填充别低于 25%
其他 | 24c_claw_finger.stl | 平行夹爪·爪指 | 2 |  | 6.0 | 26.0 | 34.0 | 4915 | 2.7 | 5.5 | 0.20 | 30% | 否 | 结构件受力，填充别低于 25%
其他 | 24d_claw_horn.stl | 平行夹爪·舵机摇臂 | 1 |  | 33.0 | 6.0 | 3.0 | 495 | 0.3 | 0.3 | 0.20 | 30% | 否 | 薄板件，切片时基本会被外壳填满；大面积要防翘边
其他 | 24e_claw_link.stl | 平行夹爪·连杆 | 2 |  | 34.5 | 6.0 | 3.0 | 543 | 0.3 | 0.6 | 0.20 | 30% | 否 | 薄板件，切片时基本会被外壳填满；大面积要防翘边
其他 | 24f_claw_gear.stl | 齿轮夹爪·齿轮 | 2 |  | 14.9 | 14.9 | 6.0 | 513 | 0.3 | 0.6 | 0.20 | 30% | 否 | 结构件受力，填充别低于 25%
其他 | 24g_claw_rack.stl | 齿轮夹爪·齿条滑块 | 2 |  | 44.0 | 15.3 | 12.0 | 6896 | 3.8 | 7.7 | 0.20 | 30% | 否 | 结构件受力，填充别低于 25%
其他 | 24h_claw_base_gear.stl | 齿轮夹爪·爪架底板 | 1 |  | 74.0 | 56.0 | 4.0 | 6775 | 3.8 | 3.8 | 0.20 | 30% | 否 | 薄板件，切片时基本会被外壳填满；大面积要防翘边
其他 | 24i_claw_finger_gear.stl | 齿轮夹爪·爪指 | 3 |  | 6.0 | 36.0 | 34.0 | 6955 | 3.9 | 11.6 | 0.20 | 30% | 否 | 结构件受力，填充别低于 25%
其他 | 26_cube_mock.stl | 26_cube_mock | 1 |  | 30.0 | 30.0 | 30.0 | 13230 | 7.4 | 7.4 | 0.20 | 30% | 否 | 结构件受力，填充别低于 25%

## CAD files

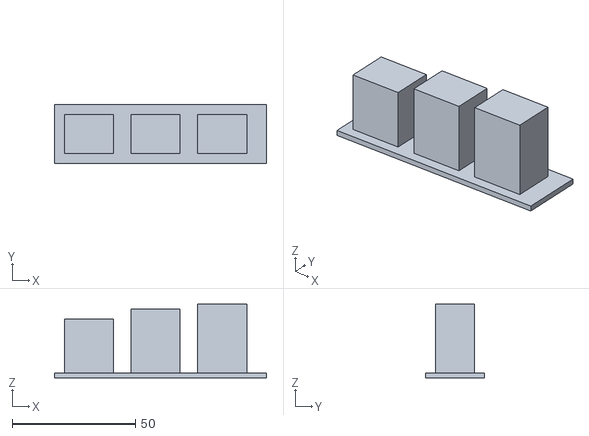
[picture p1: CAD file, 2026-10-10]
3D打印交付/00_先打这个_量板规/gauge_height.stl
86.0 x 24.0 x 30.0

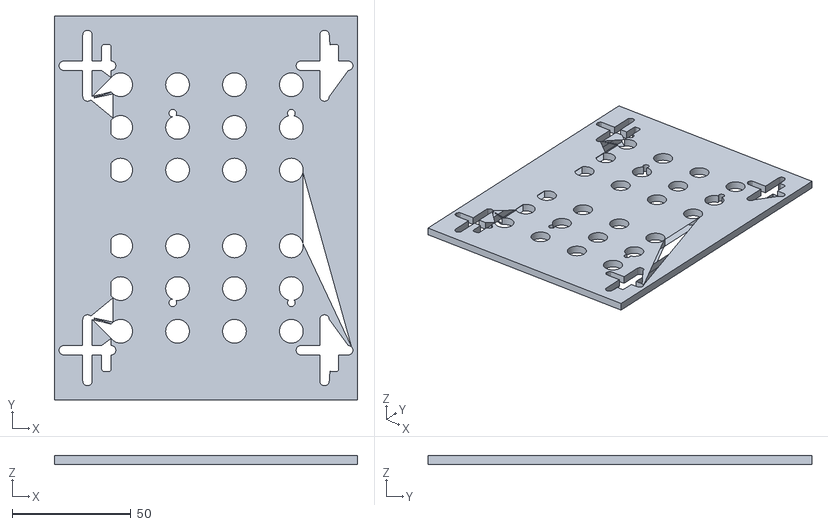
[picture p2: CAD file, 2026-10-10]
3D打印交付/01_底盘必打/02_deck_rear.stl
128.0 x 162.0 x 4.00

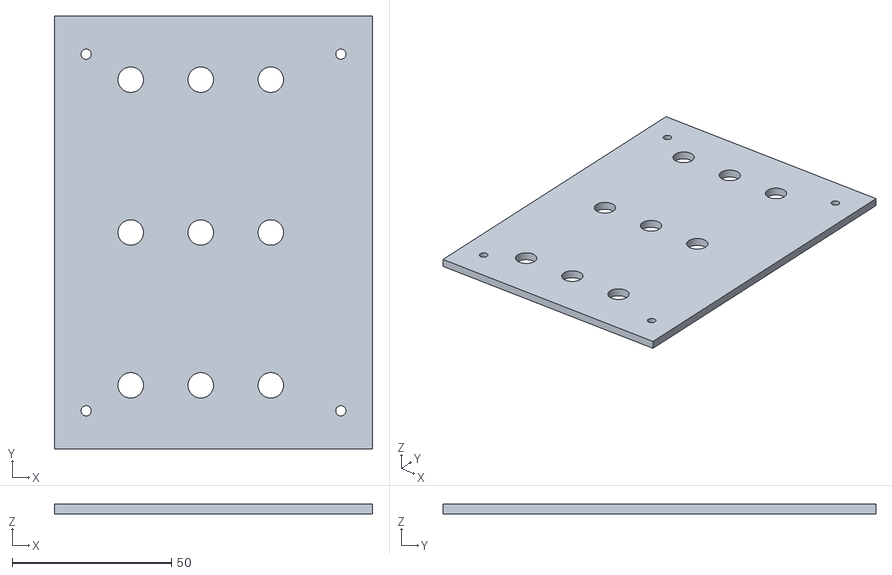
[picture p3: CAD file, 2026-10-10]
3D打印交付/02_收集与储仓/12_bin_floor.stl
100.0 x 136.0 x 3.00

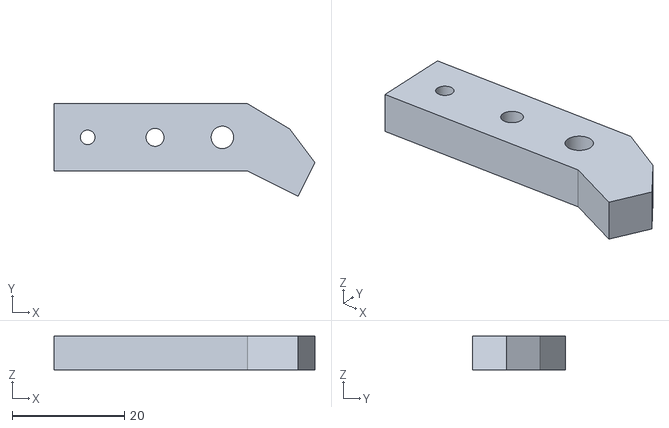
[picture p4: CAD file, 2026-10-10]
3D打印交付/03_机械臂与机构/07_grip_finger_L.stl
46.5 x 16.5 x 6.00

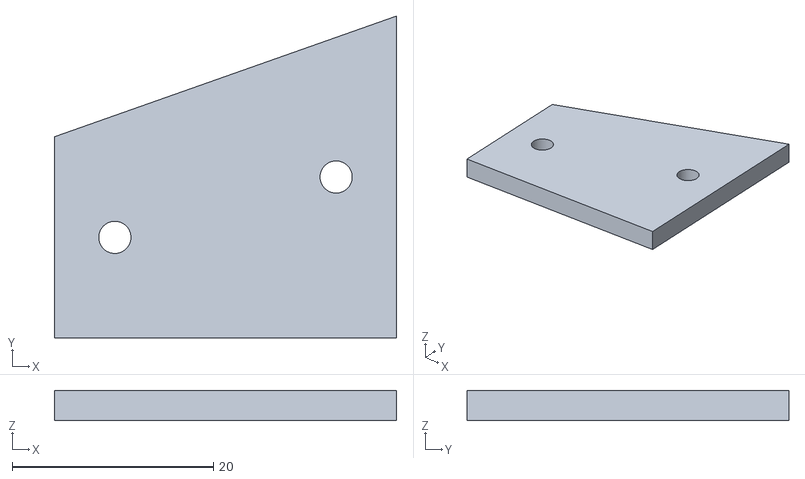
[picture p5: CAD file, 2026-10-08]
3D打印交付/04_外观套件/P5b_tail_arm_L.stl
34.0 x 32.0 x 3.00

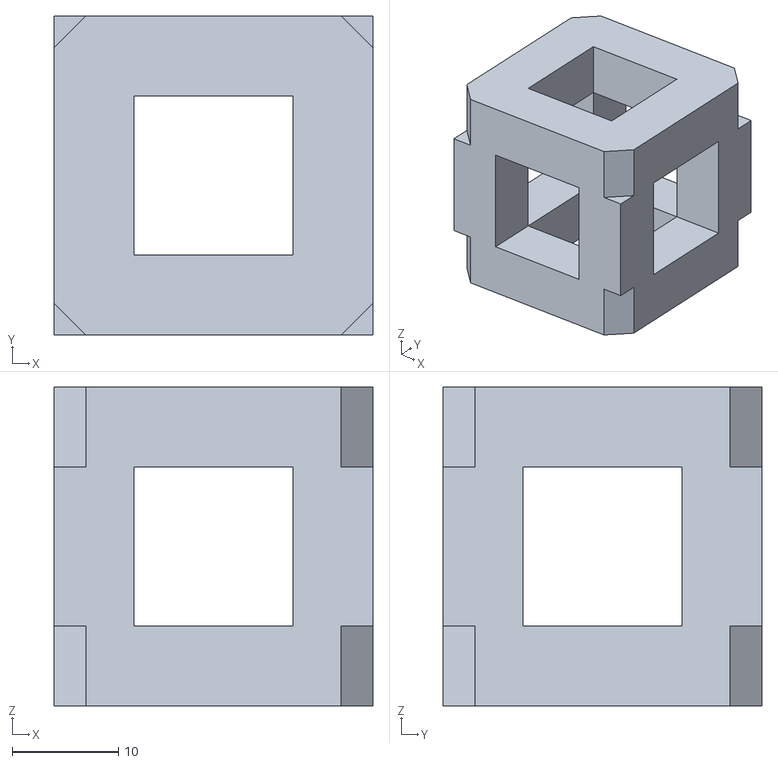
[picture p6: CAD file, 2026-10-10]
3D打印交付/06_能量块道具_拍视频用/26_cube_mock.stl
30.0 x 30.0 x 30.0

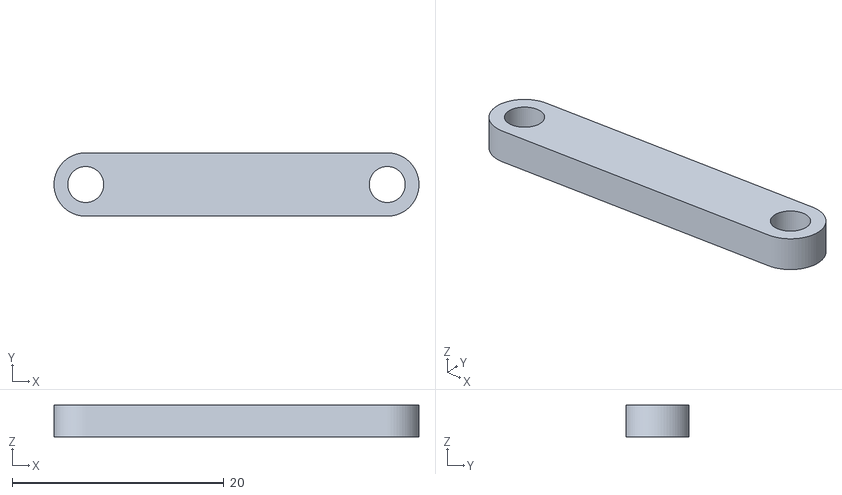
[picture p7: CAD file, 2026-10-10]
3D打印交付/07_夹爪_可选两套/24e_claw_link.stl
34.5 x 6.00 x 3.00

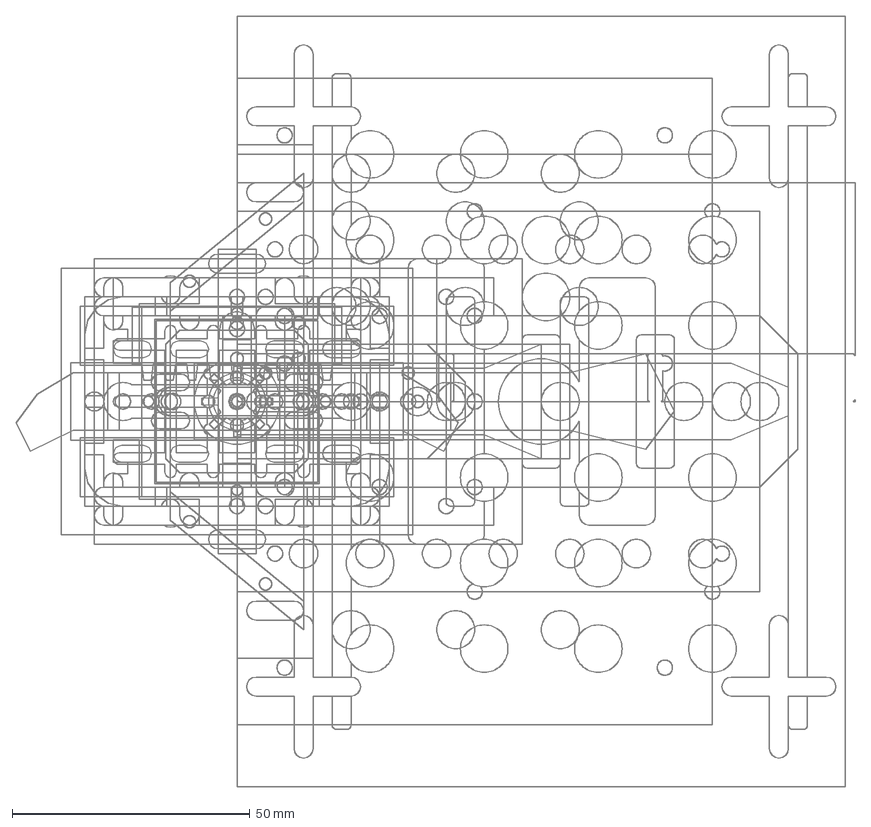
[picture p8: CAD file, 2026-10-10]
mechanical/dxf/ALL_全部零件.dxf
176.5 x 162.0 mm

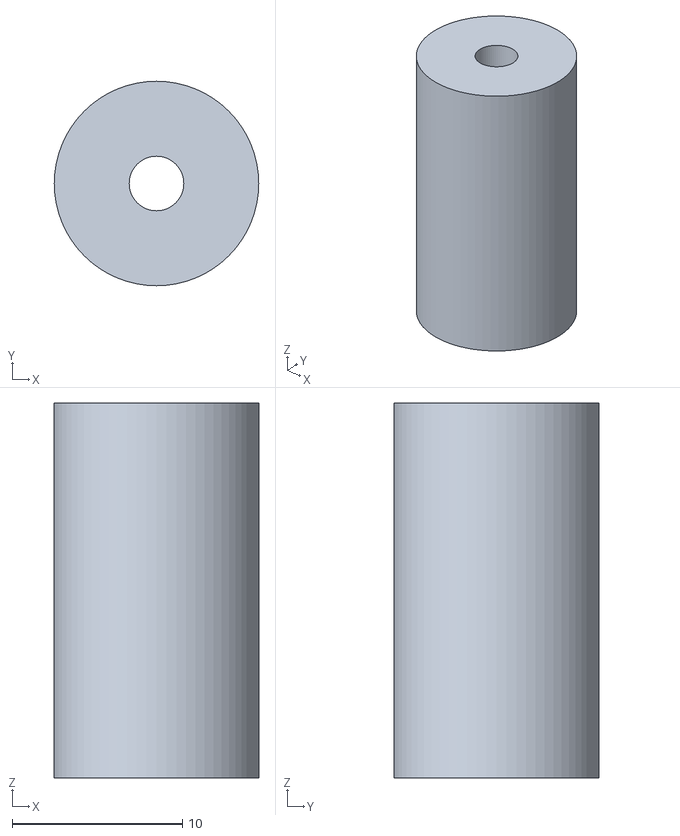
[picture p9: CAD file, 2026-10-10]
mechanical/stl/04_column.stl
12.0 x 12.0 x 22.0

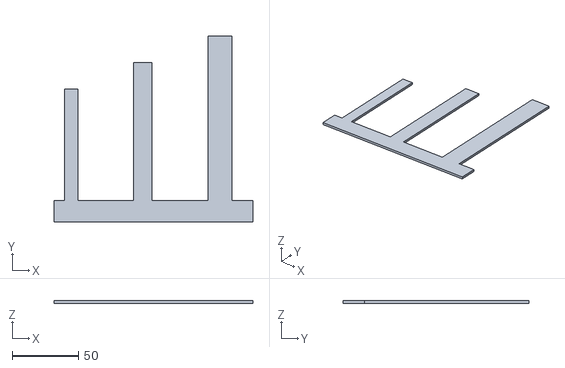
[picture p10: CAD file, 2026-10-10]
mechanical/stl_gauge/gauge_width_comb.stl
150.0 x 140.0 x 2.00

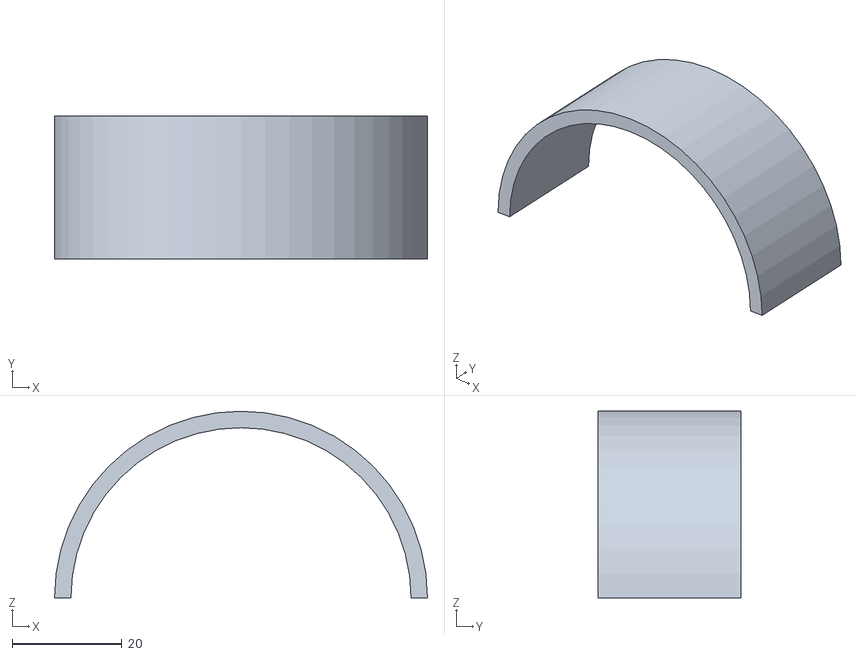
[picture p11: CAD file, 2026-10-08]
mechanical/stl_pretty/P4_fender_4.stl
68.0 x 26.0 x 34.0

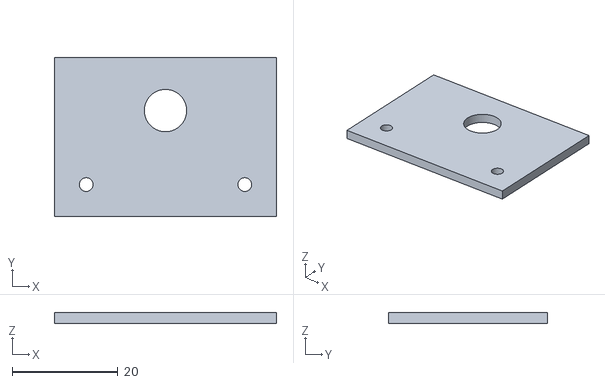
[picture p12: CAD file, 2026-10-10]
3D打印交付/02_收集与储仓/15_bin_flap.stl
42.0 x 30.0 x 2.00

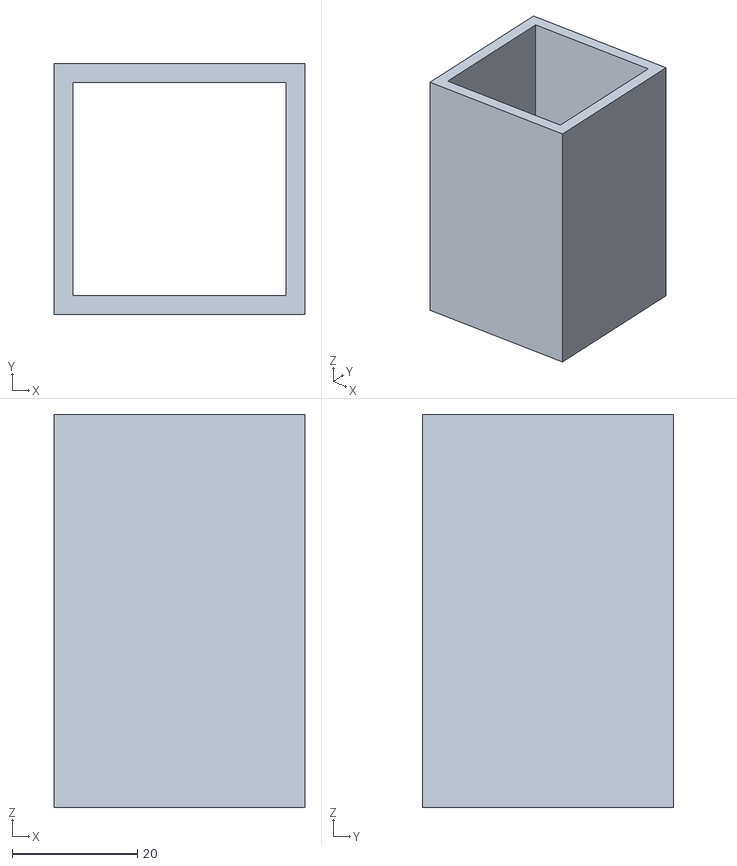
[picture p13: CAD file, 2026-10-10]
3D打印交付/03_机械臂与机构/31b_arm_mast.stl
40.0 x 40.0 x 62.7

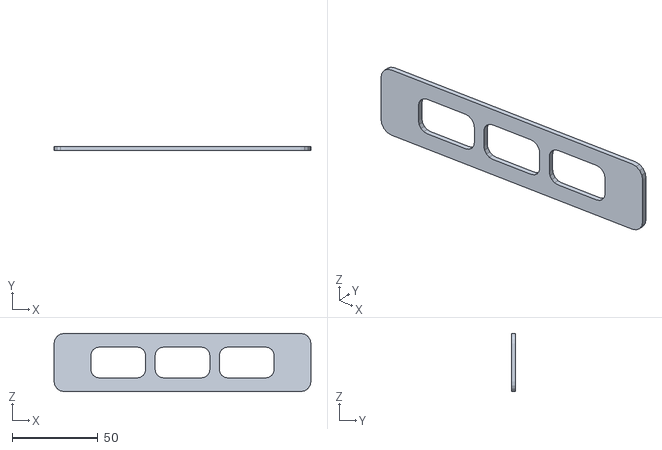
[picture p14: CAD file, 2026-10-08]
3D打印交付/04_外观套件/P2_skirt_R2.stl
150.0 x 2.50 x 34.0

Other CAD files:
3D打印交付/05_备件多打一份/08_grip_finger_R.stl
3D打印交付/07_夹爪_可选两套/24i_claw_finger_gear.stl
3D打印交付/01_底盘必打/01_deck_front.stl
3D打印交付/01_底盘必打/03_deck_splice.stl
3D打印交付/01_底盘必打/18_electronics_tray.stl
3D打印交付/01_底盘必打/19_battery_clip.stl
3D打印交付/01_底盘必打/20_bumper_front.stl
3D打印交付/01_底盘必打/21_anti_tip.stl
3D打印交付/02_收集与储仓/05_scoop_floor.stl
3D打印交付/02_收集与储仓/05b_scoop_wall_L.stl
3D打印交付/02_收集与储仓/05c_scoop_wall_R.stl
3D打印交付/02_收集与储仓/05d_scoop_back.stl
3D打印交付/02_收集与储仓/13_bin_side.stl
3D打印交付/02_收集与储仓/14_bin_divider.stl
3D打印交付/02_收集与储仓/22_ramp_anchor.stl
3D打印交付/03_机械臂与机构/06_limit_lever.stl
3D打印交付/03_机械臂与机构/08_grip_finger_R.stl
3D打印交付/03_机械臂与机构/16_rack_hook.stl
3D打印交付/03_机械臂与机构/17_cave_probe.stl
3D打印交付/03_机械臂与机构/23_cam_mast.stl
3D打印交付/03_机械臂与机构/30_arm_base.stl
3D打印交付/03_机械臂与机构/31a_arm_turntable.stl
3D打印交付/03_机械臂与机构/32_arm_carriage.stl
3D打印交付/03_机械臂与机构/33_arm_boom.stl
3D打印交付/03_机械臂与机构/34_arm_lift_crank.stl
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

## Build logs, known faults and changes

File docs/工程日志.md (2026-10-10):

# 机器人总动员战队 · 工程日志

**队伍**：机器人总动员战队（重庆大学 · 新生组）
**仓库**：<https://github.com/peach-ai280/CRTC-Robot-Team>
**更新日期**：2026-10-08

> **本文档覆盖范围**：底盘运动（电控部分）、物资采购与选型。
> 队伍里其他人负责的结构件、储仓等板块由各自在对应文档里叙述；
> 机械臂这一项，本文只写**选型依据与开源复用边界**（那是采购决策的一部分），具体设计以结构组的文档为准。

---

## 写在前面

我们这支队伍是新生队，几个人分头管：我这边管电控——**让车能按手柄动起来**，以及买需要的东西。

这份日志按**推进的先后顺序**写，**一个功能一个板块**。每个板块写两件事：这个东西要干什么，以及我们是怎么一步步试出来的。

有两条我们自己的规矩：

1. **没做完的不写成做完了。** 凡是还没上车验证的，正文里标"待实测"。
2. **卡住的地方都留着。** 调了三小时才发现的接反、想了两天才想通的限幅，我们没删。

---

## 一、底盘全向运动与麦轮防滑

### 功能描述

用四个麦克纳姆轮实现全向移动：前后、左右平移、原地自转。硬指标有两条：

- 五种动作都得能做出来；
- **横移和斜走的时候，车不能自己偏航** —— 方向一偏，后面的对位、收集全白做。

### 开发历程

**第一步：先在纸上推运动学，不着急写代码。**

麦轮的辊子是斜 45° 装的，四个轮的转速组合能合成任意方向的速度。我们按 X 型布局（左前、右前、左后、右后四个轮各自斜向不同）手推了逆解公式：给一组(vx 前进, vy 横移, wz 自转)，算出四个轮各自该转多快。

推完才发现，光有公式不够 —— 真正的麻烦在"算出来的值超过 100% 怎么办"。

**第二步：踩到最经典的一个坑——横移时车自己转圈。**

最初的写法是给四个轮**各自**限幅：谁的转速超过 1，就把它截断到 1。看着很合理，实际是错的。

原因是：当横移速度给到比较大的时候，四个轮解算出来的值大小不一，有的轮超了 1 被截掉，有的没超原样保留 —— **四个轮之间的相对比例被破坏了**，合成出来的速度方向就歪了。表现出来就是"推的是正左，车却斜着走"，转弯时车还会自己画弧。

**第三步：解法——整体等比归一化，不逐轮截断。**

改成：先扫一遍四个轮，找出绝对值最大的那个；如果它超过 1，就让**四个轮同时**除以这个最大值。

这样比例永远不变，只是整体"降速"。方向严格保住，代价是速度慢一点 —— 这个交换完全值得。

> 这是我们这个周期**最重要的一次改动**。代码在 `mecanum.c` 的 `chassis_normalize()`，一共 10 行，但它是"车能走直"和"车走不直"的分界线。

**第四步：防滑四件套。**

麦轮的辊子是塑料的、接地面积又小，比普通橡胶轮更容易打滑，尤其起步和急转的时候。我们叠了四层：

| 措施 | 解决什么 | 实现在哪 |
|---|---|---|
| 加速度斜坡（加、减速分开设） | 起步别一脚踩到底，避免轮子空转 | `chassis_ramp()` |
| 死区（油门小于 0.18 当 0） | 摇杆回中不准，导致车"自己慢慢爬" | `stick_map()` |
| 起步助力 kick | 越过死区的第一下给个短促大电流，克服静摩擦 | `motor.c` |
| 高速限自转 | 速度越高，允许的自转上限越低，防甩尾 | `chassis_limit_yaw()` |

**为什么不做编码器闭环。** 编码器要另外买、要装、要标定，我们的时间不够。开环 + 把参数调好，对"收集方块"这个精度要求是够的。**代码里留了接口**（`USE_ENCODER` 宏），以后想加随时能加。

**核心代码就四个文件**，都在仓库里可以点开看：

| 文件 | 作用 |
|---|---|
| `firmware/Core/Src/mecanum.c` | 底盘四步管线 + 麦轮逆解 |
| `firmware/Core/Src/motor.c` | 单轮输出：死区 → 起步助力 → 电压补偿 |
| `firmware/Core/Inc/config.h` | 全部运动参数（速度、加速度、限幅、符号） |
| `firmware/Core/Src/test_motion.c` | 架空测试专用固件（串口发 w/a/s/d 直接控车） |

四步管线的调用顺序在 `Chassis_Update()` 里：斜坡 → 限自转 → 逆解 → 归一化 → 输出。

**第五步：培训现场的上坡测试，暴露出一个硬问题。**

在统一培训现场做上坡测试时发现：**麦轮底盘爬不上手册里那条 300mm 坡道**，同时感觉整体"没劲"、电机发热、像是电机扛不住。

回来把数据摆出来算了一遍，结论是这个组合本身就选得不够：

| 项 | 数值 | 来源 |
|---|---|---|
| 坡道角度 | 坡高 300mm、坡比 0.5 → **26.57°** | 手册 P16 |
| TT 马达额定电压 | **3~6V** | 厂商公开参数 |
| TT 马达堵转扭矩 | 0.8 kg·cm @6V | 同上 |
| 我们实际给的电压 | 标称 7.4V / 满电 8.4V | 2×18650 |
| 我们整车设计重量 | 1.09 kg | 分项累加 |

- **扭矩**：上坡需要的每轮扭矩约 `0.34 × 车重(kg)` kg·cm。按 1.09kg 算，每轮要 0.37 kg·cm、四轮合计 1.46；而 1:48 的 TT 马达**可持续输出约 0.2 kg·cm/轮（8.4V 下约 0.28）**，四轮合计 1.12 —— **差约 30%**。
- **摩擦**：要爬上 26.57°，摩擦系数必须 ≥ tan(26.57°) = **0.50**；麦轮在地胶上的实际摩擦系数大约就是 0.5~0.7，**几乎没有余量**，地上一有灰就打滑。
- **电压**：TT 马达额定只有 3~6V，我们用 7.4V 已经是**超压约 40%**，电流和发热按比例上升，塑料齿轮箱的寿命明显缩短 —— 这就是"电机承不住"的直接原因。
- **电流**：4 个电机堵转一瞬间要 6~8A。DRV8833 单通道峰值只有 2A，正好卡在边缘，一上坡就进限流保护，表现成"一冲一冲"。

**这里我们错了一次判断**：一开始以为是参数没调好。算完才确认，**这是硬件选型的问题，光调参数救不回来**；而且**加大功率的方向不是加电压（已经超标了），而是加扭矩、减损耗**。

**对策（已列入采购，待实车复测）：**

| 方向 | 做法 | 代价 |
|---|---|---|
| 加摩擦 | 麦轮辊子套 O 型橡胶圈 / 改配 60mm 橡胶轮 | 橡胶轮会失去横移能力 |
| 加扭矩 | 换 1:120 减速比的 TT 马达（扭矩 ×2.5） | 速度从约 0.88 m/s 降到约 0.35 m/s |
| 减损耗 | 换高倍率动力 18650；电机回路改 20~22AWG 硅胶线、绕开面包板；每个 DRV8833 并 470~1000µF | 只是钱和时间 |
| 不硬碰 | 战术上先拿地面与洞穴里的道具，非必要不上 300mm 高台 | — |

> 合规性我们专门查过：手册附录注 2 写明**新生组的官方物资表只是"官方推荐"**，可以购买表外的物资；基础功能里的"底盘运动"只要求"用 PS2 手柄控制底盘的**水平运动**"，**并没有强制必须用麦轮**。所以换电机、换轮子都在规则允许范围内。电源部分仍然遵守"单一供电、额定 ≤7.4V"，**不会上 3S 或双电池组**。

**当前状态**：⚠ **代码写完、离线仿真跑过；桌面上已经跑通 ST-LINK 连接，但整车运动参数仍未经实车标定。**
车轮、电机、底板到手后，所有参数（速度增益、加速度、死区）都要**靠实车重新标定**。
详细推导和调参对照表见 `docs/03_底盘运动与麦轮防滑.md`、`docs/调参指南.md`。

---

## 二、手柄遥控与运动控制输入

### 功能描述

用官方 PS2 无线手柄遥控机器人。除了"能控"，还有一条安全要求：**手柄一掉线，车必须立刻停下来**。

### 开发历程

**协议本身：SPI 模式 3。**

手柄通过 SPI 跟单片机通信。我们用的参数是 CPOL=High、CPHA=2Edge、分频 256（约 281kHz）。

分频为什么选这么大（也就是为什么这么慢）—— 便宜手柄在 500kHz 下会偶发丢帧。轮询一帧只要 0.26ms，在 5ms 的控制周期里只占 5%，**慢一点换来不丢帧，值得**。

**最折磨人的一个坑：DI / DO 接反，查了三个小时。**

现象是串口一直收不到任何按键数据，但接线按图接的。我们依次排除了：量接收器电压（正常）、换手柄（一样）、把 SPI 四种模式组合全试一遍（一样）。

最后用示波器看波形才发现——**MISO 上一一直是高电平**，说明我们的数据线接到了手柄的"数据输入"脚上。

根源是接收器的丝印是**站在手柄角度**命名的：

| 丝印 | 含义 | 该接 STM32 |
|---|---|---|
| DI | Data In（进手柄） | MOSI（PA7） |
| DO | Data Out（出手柄） | MISO（PA6） |

我们是站在单片机角度接的，正好反了。**教训写进代码注释了：PS2 连不上，先对调 PA6/PA7，十次有九次是这个。**

**进模拟量模式。**

手柄上电默认是数字模式，摇杆只有 0 和 255 两档，没法做速度控制。必须在初始化时进配置模式，把模拟量打开。注意**配置命令之间要有延时**——我们第一版没加延时，命令全被吞了，现象是"一直停在数字模式"。

**摇杆到速度的映射，做了两件事：**

- **死区**：摇杆回中不准（中位左右各偏几个数），小于死区的一律当 0，否则车会自己爬；
- **expo 曲线**：中间段更细腻、满舵不变。这样低速对位的时候好控，又不损失极速。

**掉线保护（这条是安全底线）。**

掉线时不能只是"不再更新指令" —— 那样车里会**保留最后一次的速度一直跑下去**，直到撞墙。必须显式清零：

```c
if (!PS2_Poll()) {
    lost_cnt++;
    if (lost_cnt > 25) {        /* 约 125ms */
        connected = 0;
        btn = 0;
        lx = ly = rx = ry = 0;  /* 关键：清掉残留摇杆量 */
    }
}
```

**没有串口怎么看状态。** 板载那颗 LED 顺手写了套状态机，不接串口也能判断故障在哪：

| LED 表现 | 含义 |
|---|---|
| 常亮 | 通了（模拟模式） |
| 每秒闪 2 下 | PA6 / PA7 接反了 |
| 每秒闪 1 下 | 对面没回应（接收器没插 / 手柄没开机） |
| 每秒闪 2 下（双闪） | 数字模式，需要断电重插 |
| 全灭 | 程序没跑起来 |

**当前状态**：⚠ **这是目前唯一在推进的一环。**
SWD 烧录链已经实测打通，正在接那 6 根线做桌面测试，**还没跑到"摇杆能控车"这一步**。
接线表、LED 判读、协议细节见 `docs/05_PS2手柄与遥控器.md`。

---

## 三、桌面调试与第一次实机联通

### 功能描述

搭一套能稳定"改代码 → 编译 → 烧进板子 → 看结果"的环境。这块不直接产出功能，但**它是上面两条能推进的前提**。

### 开发历程

**不用图形界面，全部脚本化。**

本机装了 STM32CubeIDE 2.2.0（它自带 ARM 编译器和烧录器），但我们**不进它的图形界面点来点去**，而是自己写了两个脚本：

- `tools/build.py` —— 一条命令编译出固件（本机没装 make，所以自己写构建脚本）；
- `tools/flash.py` —— 一条命令烧录，自动找到 CubeIDE 自带的烧录器。

好处是：改一行参数,敲一条命令就出固件，不用等 IDE 转圈。

**自制 HAL 兼容层。**

标准做法是用 ST 官方的 HAL 库 + CMSIS，但我们这套环境拿不到。于是我们**直接操作寄存器**，自己实现了业务代码用到的 20 来个 HAL 函数，**函数名和官方一模一样** —— 这样业务代码一个字不用改，将来拿到官方库也能一键切回去。用到了哪些开源东西，见 `docs/开源项目说明.md`。

**离线验证：在电脑上跑真实固件。**

我们用 ARM 模拟器在电脑上模拟一颗 Cortex-M3，直接把编译出来的**真实固件机器码**跑起来，看电机输出对不对。这样改一个参数不用每次都烧板子试。

**实测结果（2026-10-08）：**

```
ST-LINK SN  : E1007200D0D2139393740544
Voltage     : 3.21V
Device ID   : 0x410
Device name : STM32F101/F102/F103 Medium-density
NVM size    : 128 KBytes
[OK] 芯片连上了
```

**"电脑 → ST-LINK → SWD → 芯片"整条路是通的。** `3.21V` 那行说明板子确实在从 ST-LINK 取电，芯片被正常枚举。

**为什么我们选的这条路和"官方推荐"不一样（这份说明是给评审和队友看的）。**

学院提供了一份《一个合理的工具链配置流程》，推荐的是 **CLion + STM32CubeMX + STM32CubeCLT + CubeProgrammer + CubeMonitor** 五件套。
我们没有走那条路，用的是 **STM32CubeIDE 单件**，**理由不是"图省事"，而是两条路的功能是等价的**：

| 要做的事 | 官方推荐五件套 | 我们这条路 | 是否等价 |
|---|---|---|---|
| 把 C 代码编译成芯片能执行的文件 | STM32CubeCLT | **CubeIDE 自带** `arm-none-eabi-gcc 14.3.1` | ✅ 同一个编译器 |
| 烧录到芯片 | STM32CubeProgrammer | **CubeIDE 自带** `STM32_Programmer_CLI` | ✅ 同一个烧录器 |
| 连接 ST-Link | 单独装驱动 | **CubeIDE 自带** `drivers/` | ✅ 同一份驱动 |
| 写代码 | CLion | VSCode | ✅ 等价 |
| 图形化配置芯片引脚 | STM32CubeMX | **不使用**（见下） | ❌ **有意不用** |
| 实时变量曲线 | STM32CubeMonitor | 暂不使用 | — 非必需 |

也就是说，**官方五件套里前四项的功能，CubeIDE 一个软件里全都包含了** ——
我们**没有少装什么，只是那四个东西本来就在同一个安装包里**。
这一条是实测确认过的：`D:\ST\STM32CubeIDE_2.2.0` 下的 gcc 插件与 cubeprogrammer 插件都实际存在并跑通（见上方 10-08 实测输出）。

**两条刻意的取舍**：

1. **不用 CubeMX 生成代码。** CubeMX 是"点鼠标 → 生成一堆初始化代码"，省事但学不到东西。
   我们选择自己写引脚与时钟配置，并**自己实现了 20 余个与官方同名的 HAL 函数**（见上一段的"自制 HAL 兼容层"）。
   **代价**是要自己啃寄存器手册，**收益**是每一行配置都能说清"为什么" ——
   这正是文档规范里"卓越"档（阐述技术选型对比与难点解决）所要求的内容，也是评审看重的部分。
2. **不装 CubeMonitor。** 它是用来画实时曲线看变量的，我们目前**没有需要 PID 整定或波形观测的场景**
   （底盘是开环的，见第一节）。等真正需要调试闭环时再装，现在装是白占空间。

> **一句话**：官方路线要下载五个安装包、申请一次 JetBrains 教育许可（需等 1~2 天）；
> 我们这条路只装一个，**功能覆盖其中四项，唯一舍弃的是"图形化配置"这个便利，换来的是对底层的理解**。
> 两条路不冲突，将来若想并行使用，只需改 `tools/build.py` 的编译器路径查找逻辑。

**当前状态**：✅ 环境与烧录链已实测打通；⏳ 架空测试固件（`test_motion.c`）已就绪，等电机到手即可上电验证。

---

## 四、物资采购与成本

### 功能描述

这部分是我负责的。要做三件事：**把官方给的物资清点清楚**、**算出还缺什么**、**该买的买齐**，同时不违规、不浪费。

### 开发历程

**第一步：先把官方物资表逐条核一遍，知道"不用买什么"。**

手册附录的物资表一共 18 项、两台车合计 ¥353.48（每车 ¥176.74）。逐条看完有两个直接结论：

- 底板是**一体带马达孔**的金属折弯板 → **不用打印电机座**；
- 麦轮套装里**带 TT 马达联轴器** → **不用打印轮毂**。

这一条很重要：**说明在机械臂定稿之前，我一个 3D 打印件都不需要，切片和耗材一根都不用动。**

**第二步：算缺口，查出三个官方没覆盖的地方。**

| 缺口 | 情况 | 我们的做法 |
|---|---|---|
| **USB 转串口模块** | 官方 18 项里**完全没有** | 自购 CH340 模块（¥6~8）。看不到摇杆值、占空比、电池电压就没法标定 |
| **SG90 舵机数量** | 官方每车只给 2 个，而"舵机运动（多项）"要求**同一台车 3 个同时动** | 走"两台车的舵机集中到一台车上拍"，不额外花钱 |
| **舵机 5V 供电** | 官方每车只给 1 个降压模块，它还要同时喂单片机 | 补 1 个降压模块给舵机单独一路（**分路不算违规**，规则管的是电池那一层）+ 0.1µF 瓷片电容 |

**第三步：按"现在就要用"分层买，不一次性囤齐。**

因为机械臂还没定稿，我把清单分了三档：

| 档 | 内容 | 什么时候买 |
|---|---|---|
| **桌面测试** | USB 转串口、电烙铁套装、热缩管、加长杜邦线 | **现在**（桌测用） |
| **底盘装配** | M3 螺丝螺母（含 ×8）、尼龙扎带 2.5mm | **等电机到手**（焊马达线、拧到底板） |
| **机构装配** | Φ3 光轴、M2.5 自攻、拉簧、PLA 胶、平垫圈 | **等机械臂定稿**（现在一样不买） |

**明确不买的（都写清理由）：**

- **无线继电器** —— 手册原文"**通过中期测评的队伍需要购买**"，中期这一步不买，这 ¥27.6 先不花；
- **热熔胶枪** —— 手册结构规范第 1 条明写"尽量避免采用热熔胶"；
- **电机座 / 轮毂 / 联轴器** —— 官方物资已经给了。

**第四步：培训之后，采购单上多了一组"动力改装件"。**

上坡测试出问题之后（详见第一节第五步），采购方向跟着改了。这一组不是"想升级"，是**算完发现不够用**。
分两级：第一级是"几乎一定有效"的部分，只换便宜件、**不动结构、不改运动学、横移能力保住**；第二级备用。

| 级 | 想解决 | 买什么 | 怎么选 | 预算 |
|---|---|---|---|---|
| **一** | 扭矩不够 | TT 马达 **1:120** 单轴 | ⭐ 选**免焊线版**（省掉 8 个焊点）；必须**单轴**（双轴装不进原联轴器） | ¥28~40 |
| **一** | 摩擦不够 | 硅胶 **O 型圈** | 套在麦轮小辊子上，把摩擦系数从约 0.5 提到 0.65 | ¥5~8 |
| **一** | 瞬时掉压 | 高倍率动力 18650 | 持续放电 10A 以上 | ¥30~50 |
| **一** | 线阻压降 | 22AWG 硅胶软线 | 电机回路专用，**不走面包板** | ¥10 |
| **一** | 瞬时电流 | 470µF 电解电容 | 耐压 16V 以上，每个 DRV8833 一个 | ¥5 |
| 二 | 摩擦还不够 | 60mm 橡胶轮 | 要**同径 60mm**；换上就失去横移、且要改运动学 | ¥15~25 |

**★ 一个反直觉的结论：驱动板不用换。**
DRV8833 每通道持续 1.2A，现在的问题不是它不够，而是**电机工作在接近堵转的点**，一直在抽 1.5~2A。
换成 1:120 之后，同一个坡只需要电机出它额定范围内的力，**工作电流直接掉到 0.5~0.8A** → 1.2A 的通道能力绰绰有余。
同理，主控、下载器、底板、麦轮也全部保留。

同时把三条**可能白花钱**的路排除了：**不买 3S 电池、不买升压模块**（违反"单一供电、额定 ≤7.4V"），
**不买成品套件**。选择改装件的依据不是"哪个更强"，而是**"能不能算清楚够不够，以及规则允不允许"**。

⚠ 还查清了一条容易误判的规则：手册 P9 进阶功能的排除条款里，明确把"**机器人能够上坡**"列为
"**因为没统测试条件而没有添加进基础功能的较基础的功能**"，**不能拿来报进阶功能加分**。
所以爬坡是**战术手段**（能拿高台和台阶上的道具），不是得分项 —— 这决定了我们不为它过度投入。

**第五步：采购方向随"两车差异化"的确定，拆成了两批。**

在配件取舍上，我们确定了**两台车走差异化配置**（1 号车留麦轮、2 号车换橡胶轮）。
这一步的完整推论（规则依据、指标口径、隐藏因素、清单）写在**第五节**，那是一个独立的功能板块；
这里只记它对采购的影响：**改装件的采购被拆成"中期前"和"中期后"两批**，
中期前只买 1 号车用得上的（O 型圈等），1:120 马达和橡胶轮等到中期之后再买。

**当前状态**：⚠ 采购单已出、两级分档已定；**还没下单**。
按中期的时间安排，第一级里**除 1:120 之外的四样**（O 型圈、高倍率电池、硅胶线、电容）**中期前就能用**；
**1:120 和 60mm 橡胶轮挪到中期之后再买**（理由和清单见第五节）。
方案全文见同目录 `坡道上不去与功率不够_诊断与对策.md`；其余清单见 `D:\WorkBuddy\CRTC交付\` 下的
`最终版采购清单.md`、`连接件与固定件采购单.md`、`淘宝搜索词_直接复制.md`。
另外：3D 打印件只按**原料价**计入成本（手册规定，不是按实付），一卷 PLA 只用 1/4 就算 ¥15。

---

## 五、两车差异化配置与第二台车的改装

### 功能描述

我们队的两台车**不是两台一样的车，是两种车**：

- **1 号车（麦轮车）**—— 要它的**全向移动**。负责平地范围、以及一切需要**精细对位**的活：
  平地白块、桥下（净高 130mm）的白块、洞穴探杆、矮墙槽（31.5mm）的垂直对位。
- **2 号车（橡胶轮车）**—— 要它的**抓地力**。只走前后和转向，不去挤窄缝，
  专职**爬 26.57° 坡道、上 300mm 高台**，拿高台面的方块和中央高地的焦点能量核心。

这个分工的由来很简单：**没有任何一种轮子能同时"全向精确"和"能爬陡坡"。**

| | 麦轮 | 普通橡胶轮 |
|---|---|---|
| 全向横移 | ✅ 能 | ❌ 不能 |
| 在地胶上的摩擦系数 | 约 0.5~0.7 | 约 0.8~1.0 |
| 能否爬 26.57° 坡（需 μ≥0.50） | ⚠ **临界，几乎没余量** | ✅ 有余量 |

所以让两台车各拿一头，而不是把两台车都改成同一种。

### 开发历程

**第一步：确认"两台车不一样"这件事规则允不允许。**

在决定换轮之前，先把这个问题查清楚，免得白改。查完的结论是**允许**：

- **P6「机器人设定」**只按**启动区**定义 1 号 / 2 号机器人，**没有一个字**要求两台车同构型；
- **P9「考核指标一览」开头那行注**写的是"数量均以参赛队**所有机器人的总体数量**来计算"
  —— 如果强制两台车一样，这句话就没有存在的必要；
- 反过来，手册确实有两条硬要求：**两台车都要通过检录**（"所有参赛机器人均未通过赛前检录的队伍成绩直接判负"）、
  **每台各自满足通用规范**（每台 1 个供电模块、额定 ≤7.4V、能被无线继电器 10m 断电、初始尺寸 290×195×210）。

**第二步：确认中期的时间安排——中期只做 1 号车。**

我们的实际情况是：到 10-19 中期截止，能做出实物演示的只有 1 号车。所以安排是：

- **中期前**：集中把 1 号车（麦轮）做完整；
- **中期后**：确认过了中期，再动手做 2 号车的橡胶轮改装。

这不是"放弃 2 号车"，是**排优先级**。理由：中期考核**允许不产出实物演示**，
而且**做不到的指标不报就是，不倒扣分**，所以为了一台来不及的车去拖累 1 号车的调试，不划算。

**第三步（重要，改变了采购计划）：报"底盘运动（全部）"其实不需要换橡胶轮。**

又把 P9 的指标原文读了一遍，发现"底盘运动（全部）"的原文是：

> "能使用 PS2 手柄控制**全部车体**的水平运动（需保证车体与 PS2 手柄同时出镜或给出相关代码）"

它要求的是"**全部车体都能水平运动**"，**并没有要求第二台车有机械臂、有储仓、或者换了橡胶轮**。

于是得到两个结论：

1. **换橡胶轮是为了战术收益**（能上高台拿道具），**跟考核指标是两回事**。不换轮，指标 7 一样能报。
2. 只要**第二台车能通电、能用手柄走起来**（哪怕是个裸底盘），就可以报"底盘运动（全部）"。
   而第二台车的裸底盘——**底板、4 个马达、4 个麦轮、2 个 DRV8833、1 个降压模块，官方物资表按两台车的量都给齐了**，
   差的只是装配工时。

所以中期前的真实目标被修正为：**1 号车做完整 + 尽量让 2 号车的裸底盘也能跑**。
如果实在来不及，就**只报"底盘运动（单一）"**，不报的那一项不扣分。

**第四步：第二台车真的要换橡胶轮时，要额外买什么。**

官方物资表是**按两台车**给的（8 个 TT 马达、2 套麦轮、4 个 DRV8833、2 个降压模块），
所以换轮**不需要重买底盘和电控**，只需要补这些：

| 要买的东西 | 规格要求（照着选，别选错） | 为什么要它 | 估价 |
|---|---|---|---|
| TT 马达 **1:120** 单轴 ×4 | ⭐**免焊线版**（省掉 8 个焊点）；**必须单轴**（双轴装不进原联轴器） | 扭矩从 0.8 提到约 1.5 kg·cm | ¥12~20 |
| **60mm 橡胶轮** ×4 | ⭐**必须买"TT 马达专用 D 型孔"款**；外径**同 60mm** | 摩擦系数 0.5→0.9 | ¥12~20 |
| 高倍率**动力 18650** ×2 | 持续放电**10A 以上** | 堵转瞬间不掉压 | ¥30~50 |
| **22AWG 硅胶软线** 约 2m | 多股软线 | 电机回路专用，**不走面包板** | ¥10 |
| **470µF/25V** 电解电容 ×2 | 直插 | 2 号车两个 DRV8833 各并一个 | ¥3 |

**明确不用买的**（官方已经给足了，这是省钱的关键）：

- ❌ 金属底板、❌ DRV8833、❌ 降压模块、❌ 电池盒、❌ 充电器 —— 官方物资表**都是两台车的量**；
- ❌ ST-LINK、❌ PS2 手柄 —— **官方给了 2 个手柄**（见下面"隐藏因素"第 1 条）；
- ❌ 电机座 / 轮毂 —— 金属底板一体带马达孔；麦轮套装里**自带了 TT 马达联轴器**。

**第五步：把可能踩坑的地方一条条过一遍（这一步花的时间比前四步加起来还多）。**

| # | 隐藏因素 | 会怎么坑人 | 我们的结论 / 待办 |
|---|---|---|---|
| 1 | 手册写"确保信号的**发射源与接收源有且仅有一组**" | 一度以为"一队只能用一个手柄"，那两台车就没法分别控制 | ✅ **官方物资表给的是 2 个 PS2 手柄（¥45×2）** → 官方默认就是**每车一个**。那句话指的是"通信方式只能选一种（2.4G/蓝牙/WiFi/红外 四选一）"，不是限制手柄数量。**仍然建议在群里问一句留个底** |
| 2 | 重量上限 **2.0kg** 是"每台"还是"两台合计" | 影响配重和能不能上臂 | 原文在 P7「规格规范」下，与"初始长宽高"并列，且后面紧接"注：初始尺寸指每次对局正式开始时机器人的尺寸" → **是每台 2.0kg** |
| 3 | 成本 400 元是"每台"还是"合计" | 影响能不能买改装件 | 原文"**每支队伍**机器人造价总成本不推荐超过 400 元" → **两台车合计**。所以改装件要算进来（见下） |
| 4 | **麦轮和橡胶轮的"接地高度"可能不一样** | 麦轮是**斜辊子**结构，标称 60mm 不等于实际支撑高度；换成刚性圆轮后车会变高或变矮 | ⚠ **必须实测**：装了麦轮的车，量一次板面离地高度；换成橡胶轮后再量一次。**高度栈会跟着变** |
| 5 | 麦轮和橡胶轮的**轮宽**不一样 | 底板孔位是按麦轮的位置定的，橡胶轮可能装不上同一位置 | ⚠ 待实测；**固定方式优先用十字槽 + 扎带**，不依赖现成孔位 |
| 6 | 橡胶轮摩擦更大 = **更容易堵转** | 摩擦不再打滑之后，扭矩成了唯一下限，马达更容易憋住 | 已在计划内：**1:120 是必须项，不是可选项** |
| 7 | 1:120 减速比 = **速度掉一半**（0.88→约 0.35~0.40 m/s） | 2 号车跑一趟高台来回会慢 | 可接受：2 号车只跑坡道到高台这一段短距离。**如果后续觉得太慢，再考虑 1:90** |
| 8 | 两台车同时上场，**两个手柄会不会互相干扰** | 己方 2.4G 互扰 | 官方手柄是**可对频锁定款**，风险低；仍列为**待实测**（同时开机试一次） |
| 9 | **备用机器人也要过检录** | 备用车不合规会让上场车也受影响 | 中期阶段不做备用车，暂不涉及 |
| 10 | 手册要求**仓库名用队伍名称的英文或拼音** | 我们现在的仓库名是 `CRTC-Robot-Team`，**不是队伍名的英文/拼音形式** | ⚠ **待确认**：需要用报名时登记的队伍英文名，或改成拼音（如 `jiqiren-zongdongyuan`）。**这个要在中期提交链接之前定下来** |
| 11 | 塑料齿轮的**承受限度** | 1:48 是塑料齿轮，长期超压（8.4V vs 额定 6V）运行会磨 | 1 号车**巡航档占空比限到 0.75**（电机端约 6.3V，不超额定），只在需要冲刺时给满 |
| 12 | 1:120 扭矩大，**卡住时会持续堵转** | 烧马达或拉爆驱动 | 软件上加**堵转超时保护**（占空比给满但转速为 0 超过 N 秒就降功率） |

**第六步：算成本（两台车合计必须控制在 400 元以内）。**

官方物资表 **¥353.48 就是两台车的量**。所以自购部分只剩约 **¥46** 的余量，
这就是为什么第二台车的改装件要压到最低——**优先买 ¥12~20 的 1:120 和 ¥12~20 的橡胶轮**，
高倍率电池、电容、硅胶线这些能复用桌面测试那批就复用。

**当前状态**：⚠ 中期前**只做 1 号车**；第二台车的改装件（1:120、橡胶轮）**先不下单**，
等中期结果出来再买。1 号车现在要买的只有麦轮防滑用的 **O 型圈（约 ¥5）** 和桌测那几样。

---

## 六、机械臂：照参考视频确定的"平行四连杆"方案

> ⚠⚠ **本节已被 `## 十一` 取代（2026-10-10 第三次大改）。**
> 这里的"平行四连杆"是把参考视频**读错了**得出的方案 —— 视频里那根是
> **竖直立柱 + 柱上滑座**（圆柱坐标），不是"矮座 + 长臂绕水平轴摆"。
> 本节按"不重写历史"的约定保留，但**其中的尺寸、件号、结论一律作废**，
> 凡看到 `09_arm_upper` / `10_arm_fore` / `11_servo_horn_plate` / `11b_claw_adapter` /
> `25_arm_riser` / `32_arm_link` / `33_arm_elbow` 都是这一代的遗物。

### 功能描述

两台车**各装一台机械臂，用同一款设计、同一套代码、同一张姿态表**。结构上照队内参考视频确定为
**盒式臂座 + 平行四连杆臂 + 末端平行爪**：

```
                ┌── 从动轴 A′ ──┐
   肩架竖板 ────┤               ├──── 平行杆 A′→B′ ┐
                │               │                   ├── 肘座（姿态恒定水平）
                └── 主动轴 A ───┘                    │
                    （MG995 驱动）  └── 主臂 A→B ────┘
                                                        └── 平行爪（爪指永远朝下）
```

**它凭什么"爪子永远水平"**：主臂 A→B 与平行杆 A′→B′ **等长（105mm）且始终平行**，
于是四边形 A-B-B′-A′ 永远是平行四边形 → **肘座的姿态永远和肩架一样（水平）**
→ 装在它下面的爪指永远朝下。

**三个动作、三个舵机**（正好满足中期指标 5「同一台机器人 ≥3 个舵机」）：

| 编号 | 型号 | 装在哪 | 负责的动作 |
|---|---|---|---|
| S1 | **MG995** | 臂座内腔（侧躺），驱动主动轴 A | 整条臂在**竖直平面**内上下摆（φ = −50° ~ +90°） |
| S2 | **SG90** | 臂座内腔上部，轴朝上，驱动回转盘 | 整条臂绕**竖直轴**回转（工作 ±120°，收起 180°） |
| S3 | **SG90** | 趴在平行爪底板上 | 齿轮版平行爪开合 |

> 整车实际是 **5 路舵机**（臂 3 + 前铲 1 + 洞窟探杆 1），比指标要求的 3 个还富余。

**这台臂能拿什么、不能拿什么**（这一节的核心结论，全部经脚本数值复算）：

| 目标 | 需要摆角 φ | 结论 | 实际怎么处理 |
|---|---|---|---|
| 地面白块（a8/h1/c4/f5） | 需 φ ≤ −60° | ❌ | **全部交给前铲**——φ 到 −50° 主臂就扫到收集铲了 |
| 台阶面白块（e8/d6/e3/d1，离地 150~180mm） | φ = +18.0° ~ +20.3° | ✅ | 车停台阶下，臂朝前摆到 φ=+19° 夹 |
| 中央高台面白块（相对车底板 135~165mm） | φ = +9.6° ~ +11.8° | ✅ | **车先走桥上台面**，再摆 φ=+11° |
| 焦点黄块（相对车底板 70~100mm） | φ = −26.9° ~ −24.5° | ✅ | 车停焦点旁，臂下压到 φ=−26° |
| 物资架黄块（离地 235~265mm） | φ=+90° 时只重叠 17.5mm | ⚠ **半** | 只能夹住下半截；先用爪沿 φ14 圆柱往外拨再夹。**取不下就放弃**（队内已确认） |
| 洞穴黄块（洞 70×70×50） | — | ❌ | **爪外宽 74 > 洞宽 70，爪进不去** → 改用洞窟探杆 `17_cave_probe` |

**尺寸包络（收起 = 检录位）**：全车长 **282.5mm**（红线 290）、最高 **196.5mm**（红线 210）、
爪最低点 113.5mm。收起姿态是「**yaw = 180° 朝正后方 + 摆角 φ = 0° 水平平躺**」。

### 开发历程

**第一步：从"最高要够到 250mm"反推杆长（90 → 105mm）。**

最初的硬需求只有三条：方块 30×30×30（白黄同规格，一个夹爪通吃）、**最高够到 250mm**（物资架质心高度）、
收起来后整车回到 ≤210mm 高、≤290×195 长宽。

第一版主臂孔距取 **90mm**。用脚本验算发现：把摆角顶到固件上限 +90°，
夹持缝最高也只到 243mm，而物资架黄块占 235~265mm —— **完全够不着**。
杆长提到 **105mm** 后，φ=+90° 时夹持缝为 `[218.5, 252.5]`，与黄块**重叠 17.5mm**，
从"完全够不着"变成"够得着、但只夹得住下半截"。这一条仍不理想，所以明确放弃。

**第二步：收起姿态从"朝前下倾 45°"改成"朝后平躺"。**

第一版想让臂朝前下倾 45° 收在车头。验算发现两个硬伤：
① 爪会伸到 x=+152，**车长从 283mm 冲到 300mm，超过 290 红线**；
② 车头 x=+124.5~+152.5 是前铲的地盘，**臂和铲抢空间**。

改成「yaw=180° 朝正后方 + φ=0° 水平平躺」后：臂整条躺在车体上方，
**车长还是 283mm（和没装臂一样）**，车高由竖板顶 196.5mm 决定（余 13.5mm）。

**第三步：高度栈与限高（`AB_SERVO_DZ` 10 → 18mm）。**

高度栈是：金属底板面 62.5 → 立柱 22 → 甲板面 **88.5** → 臂座高 50（座顶 138.5）
→ 回转盘 8（盘面 146.5）→ `AB_SERVO_DZ` → 主臂轴 A.z → 从动轴 A′.z（+24）→ 竖板顶。

`AB_SERVO_DZ` 最初取 10，但 MG995 侧躺时**本体高 36mm**，轴心在正中间，
半高就是 18mm。取 10 的结果是**本体下沿比盘面低 8mm，扎进回转盘里，装不进去**。
改成 18 → A.z = 164.5、A′.z = 188.5、**竖板顶 196.5 < 210（余 13.5mm）**。
这一步是踩过坑的，所以记下纪律：**这个数只能加不能减，改了要连带竖板高度一起重算。**

（另外，臂座沿车长的长度**刻意压到 34mm**：做长了主臂往下摆时会打到臂座自己的前壁，
φ 刚到 −26° 就被自己挡住。压扁的代价是 MG995 只能侧躺，而这又反过来决定 `AB_SERVO_DZ`。）

**第四步（本轮最关键的一处修正）：储仓让位——爪指会扎进旧储仓。**

臂朝后平躺之后，以回转轴 `AB_AX=106` 为圆心、水平伸出 `18+105=123mm`，
**爪子中心落在 x = 106 − 123 = −17**。而第一版把储仓放在车尾 `x ∈ [−118, −18]`，
爪的**两根手指**（`x ∈ [−36,−30]`、`[−4,2]`）正好**扎进储仓最后一列方块上方 8mm，撞了 2 格**。

这三条修法一起做（缺一条都不行）：① 储仓**整仓前移到 `x ∈ [−32, +68]`**；
② 中间 4 根立柱从 `x=±4` 挪到 **`x=−45 / +78`**（让出甲板中段）；
③ 储仓**最后一列中两排刻意留空**当爪的停车位（12 位里只用 10 位）。
复算结果 **0 干涉**，而且捡到一个好处：爪停靠点正在储仓最后一列正上方，
投料**落差只有 22mm**，是全仓最温和的投料位。

> ⚠ 这一处最早靠"看图纸"判断为"不相交"——因为只比了两个剖面的**高度**，忽略了爪的**宽度**。
> 写了 `tools/check_arm_clearance.py` 才把它抓出来。详见 `docs/批判与修正记录.md`。

**第五步：诚实地算一下它到底能有多准（这一条决定了我们不去报"精准抓取"）。**

舵机是**开环**的，没有任何角度回读：

| 环节 | 典型误差 |
|---|---|
| MG995 定位（金属齿轮，靠电位器） | ±1°~2° |
| SG90 定位（**塑料齿轮，虚位大**） | ±3°~5° |
| 折算到臂端（臂长 105mm，**1° ≈ 1.8mm**） | 累计 **±5~10mm** |
| 夹爪能容忍的偏差 | 约 **16mm**（喉口 46.4 vs 方块对角线 42.4） |

结论：**能抓，但没有多次重复的把握。** 所以策略是"机械对中优先"：
爪口做喇叭口导向把误差吃掉、**固定姿态抓取**不做中途解算、**靠底盘对位而不是臂对位**；
❌ **不把"精准抓取"当进阶功能报**——开环臂做不出可复现的精度，报上去反而扣分。

**第六步：开源方案调研，以及"能用多少"的边界。**

| 开源方案 | 许可 | 我们打算怎么用 |
|---|---|---|
| **MeArm**（经典 4 自由度舵机臂） | MIT | 参考它的**连杆几何**与**舵机姿态角标定方法** |
| **EEZYbotARM MK2**（3D 打印舵机臂） | CC BY-NC-SA | 参考它**用平行四边形保持末端姿态**的思路 |
| 通用"舵机 + 码盘 + 平板件"公开教程 | 无特定许可 | **主要参考对象** |

⚠ **关键边界：不能直接搬用现成 STL。** 车长只剩 7mm 余量、高度栈被轮径锁死，
现成模型是按它自己的底盘设计的，硬搬会直接让整车超尺寸。
所以做法是：**参考开源的连杆原理和标定方法，尺寸全部自己出。**
（若后续真采用了某个开源模型或代码，必须回到第十一节补完整说明——这是手册硬要求。）

**第七步：第 5 路舵机的通道选择（TIM3 方案整个作废）。**

臂要回转，需要第 5 路 PWM。第一版查表发现 **TIM3 全空闲**，就想用 TIM3——
但这只看了定时器、没看引脚，**TIM3 的三组引脚其实全部撞车**：
不重映射是 PS2 的 MISO/MOSI；部分重映射是按键 / PS2 片选 / 电池 ADC；
全重映射的 PC6~PC9 蓝丸板根本没引出。改用 **TIM1_CH4 = PA11**：
不用重映射、不撞外设、板上引出来了。

连带发现：**TIM1 是高级定时器，不置 `BDTR.MOE`(bit15) 所有通道会被硬件强制关断**
（寄存器全配对了、示波器上也没波形），已在 `hal_shim.c` 里补上；
另外 **PA11/PA12 同时接在蓝丸的 micro-USB 座上（D−/D+），调车时不能插 micro-USB 供电**。

**当前状态**：机械臂结构参数（`mechanical/gen_parts.py` §5.7）、装配与运动范围
（`CRTC交付/机械臂_装配与运动范围.html`）、修正记录（`docs/批判与修正记录.md`）均已定稿。
固件 5 路舵机改造完成，`python tools/build.py all` 六个目标全部编译通过。
**待实测**：收起态实际总高、爪回转 180° 后是否真落在储仓停车位、夹爪实际净距、
物资架"先拨再夹"能否成功。

---

## 七、两台机器人的物块获取方式与运动学分工

### 功能描述

按前面的分工，两台车的物块获取方式不一样，这不是"顺手做两套"，是**场地逼出来的**：

| 车型 | 获取方式 | 自动化 | **负责的物块** |
|---|---|---|---|
| **1 号车**（麦轮） | **前铲抬块 + 吞噬入仓**：车头前铲带 20° 抬升斜面，贴地把方块铲起、顺势推进仓内 | **半自动**（×1.5 / ×1.25） | 平地白块、桥下白块、洞穴黄块——**数量和重复度最高** |
| **2 号车**（橡胶轮） | **机械爪抓取**：标准臂 + 夹爪，配合差速转向对位 | **半自动**（建议，见下） | 物资架黄块、中央焦点黄块、高台面白块——**位置最难、分值最高** |

两台车的**运动学内核不同**：1 号车是麦轮（能横移），2 号车是橡胶轮（不能横移，只能差速/滑移转向）。
代码是**同一份源文件**，差别只有一个编译宏。

### 开发历程

**第一步：为什么 1 号车不能"夹"，只能"推"。先算缝隙。**

场地上的方块不是散放的，很多卡在两片矮墙之间的槽里。手册 P16 写了两处矮墙的尺寸：

| 位置 | 矮墙规格 | 组内间距 | 方块边长 | **单边缝隙** |
|---|---|---|---|---|
| e8、d1 附属高台的矮墙 | 10×50×10mm | **31.5mm** | 30mm | **(31.5−30)/2 = 0.75mm** |
| 中央焦点基座的矮墙 | 10×60×10mm | **31.5mm** | 30mm | **0.75mm** |

**0.75mm。**任何爪指都塞不进去（最薄的打印件也在 2mm 以上）。
所以：

- ❌ **从侧面伸爪进槽里夹** —— 物理上不可能，别试了；
- ❌ **从上方垂直下爪** —— 也得塞进这 0.75mm，同样不现实（这修正了我们更早笔记里"只能垂直夹"的说法）；
- ✅ **从下往上抬 + 平推** —— **方块高 30mm、矮墙只有 10mm**，只要抬起来 20mm 以上就脱离限位了。**这是唯一合理的物理路线**。

**第二步：抬升要推多远？把楔形斜面算清楚。**

前铲做成一斜楔，往前推的时候把方块沿斜面抬起。要让方块底面越过 10mm 矮墙顶：

| 楔角 | 需要水平推进距离 |
|---|---|
| 15° | 37.3 mm |
| **20°** | **27.5 mm** |
| **25°** | **21.4 mm** |
| 30° | 17.3 mm |

选 **20°~25°**：行程合理（车前进 25mm 左右就够），又不像 30° 那样把方块"顶飞"出槽。

**第三步：三个硬约束，缺一个这个方案就是废件。**

**约束一：车长只剩 7mm，前铲绝对不能再加长。**

| 项 | 数值 |
|---|---|
| 当前车长（含铲） | 283 mm |
| 检录红线（初始尺寸） | **290 mm** |
| **余量** | **7 mm** |

直接把 20mm 的斜面接到车头外面 → 303mm，**超限 13mm，检录直接不合格**。
三条解法（**都不是加长**）：

- ✅ 把斜面**做进现有 283mm 内**——缩短铲斗平段，给斜面让位；
- ✅ 做成**折叠/伸缩铲**：检录时收起（尺寸合规），比赛时展开；
- ✅ 干脆不做独立斜面，用**带倾角的抬升铲**本身当斜面（平移到方块底下 → 抬起 → 正好是 20° 楔角）。

**约束二：斜面必须从离地 0mm 起步。**
附属高台只比地面高 20mm，矮墙立在地面上。如果斜面最前端离地太高，车头会直接**撞上矮墙侧面**而不是骑上去。
→ 斜面尖端必须贴地。

**约束三：附属高台只有 160mm 长、50mm 宽，容错极小。**
车要在这么窄的台上走位，还得把铲尖对准 0.75mm 级的缝。
→ 手动基本做不到，必须靠**机械对中（喇叭口导向）**；这也是**给 1 号车保留麦轮**的理由之一——它能横移微调。

**第四步：2 号车换橡胶轮之后，运动学的代码必须换。**

这是最容易出事、也最容易糊弄过去的一步。**橡胶轮和麦轮不能共用一套公式**：

```
麦轮逆解（1 号车，现有实现）：
  w_LF = vx − vy − (a+b)·ω
  w_RF = vx + vy + (a+b)·ω
  w_LB = vx + vy − (a+b)·ω
  w_RB = vx − vy + (a+b)·ω

差速/滑移转向（2 号车，橡胶轮）：
  w_左 = vx + K·ω          K = 半轮距 / 轮半径
  w_右 = vx − K·ω
```

**为什么"照抄麦轮"是灾难**：麦轮公式里那个 `vy` 项，在橡胶轮上**没有对应的物理自由度**。
如果照抄，手柄一推横移，四个轮子会**两两反向对打**——车原地抽搐、电流翻倍、位置一动不动，
而且**不会报错**，只会让人以为是"车没劲"。

**TURN_K 怎么来的**：车要原地转 ω（rad/s），左右轮心画的是半径等于"半轮距"的圆，
线速度 = ω × 半轮距（m/s）；但电机看的是**轮子转多快**（rad/s），所以再除以轮半径。
合起来 K = 半轮距 / 轮半径，**是个无单位的纯几何系数**。
⚠ 换轮子必须同步改轮半径，否则转向量直接算错。

**第五步：两套运动学怎么共用一份代码（这是报"底盘运动（全部）"的证据）。**

我们用**编译期开关**：

```c
/* firmware/Core/Inc/config.h */
#define CHASSIS_TYPE_MECANUM  0     /* 1 号车：麦轮，全向 */
#define CHASSIS_TYPE_DIFF     1     /* 2 号车：橡胶轮，差速 */
#ifndef CHASSIS_TYPE
  #define CHASSIS_TYPE        CHASSIS_TYPE_MECANUM
#endif
```

```c
/* cpp/src/chassis.cpp —— 外圈三步两台车完全相同，只有第三步换内核 */
void Chassis::kinematics(void)
{
#if CRTC_IS_DIFF()
    kinematicsDiff();        /* 橡胶轮：左右分组 */
#else
    kinematicsMecanum();     /* 麦轮：对角分组 */
#endif
}
```

**两台车用的是同一份源文件、同一份参数表**，只有运动学那一行不同。
这也是我们后面能坦然地报"底盘运动（全部）"的原因——**代码层面它就是一套，不是拿两台不同的车凑数**。

**第六步：验证。不是"看着对"，是四道检查都过了。**

（1）**编译**：C 版和 C++ 版都编出两套固件，**体积不同**（说明真的编进了不同代码）：

| 版本 | 1 号车（麦轮） | 2 号车（差速） |
|---|---|---|
| C（`firmware/`） | `text 21564` | `text 21060` |
| C++（`cpp/`） | `text 24848` | `text 24792` |

（2）**符号表互斥检查**：1 号车固件里**只有** `Chassis_*`，2 号车固件里**只有** `Diff_*`，互不出现：

```
B 车固件有 kinematicsDiff    : True
A 车固件有 kinematicsDiff    : False
A 车固件有 kinematicsMecanum : True
B 车固件有 kinematicsMecanum : False
B 车固件有 turnK             : True
A 车固件有 turnK             : False
```

（3）**模拟器数值对比**（同一份手柄输入，看四轮输出）：

| 输入 | 1 号车（麦轮） | 2 号车（橡胶轮差速） |
|---|---|---|
| 前进 vx=1 | 四轮 `+0.850` | 四轮 `+0.850` ✅ **完全相同** |
| **横移 vy=1** | `−0.850 +0.850 +0.850 −0.850`（**真的横移**） | **四轮全 0**（橡胶轮没有这个自由度） |
| 自转 wz=1 | `−0.474 +0.474 −0.474 +0.474`（**对角分组**） | `+1.000 −1.000 +1.000 −1.000`（**左右分组**）✅ |
| 斜走 vx=vy=0.707 | `0 +1 +1 0`（保住 45°） | 四轮同值，**只剩前进分量**（方向会偏，是丢 vy 的必然代价） |

两车自转的形式**一眼可辨**：麦轮是"左前/右后一组、右前/左后一组"的对角关系，
差速是"左侧一组、右侧一组"的左右关系。这是判断"到底有没有真的用上差速内核"最直接的办法。

（4）**模拟器自检全绿**：`python tools/sim/run_cpp_sim.py a` 和 `... b` 两个入口都是
`RESULT: ALL PASS (fail=0)`，共 30 多项断言。

**第七步：路上抓到的两个真坑（写下来给自己和队友看）。**

**坑一：新加的源文件不会被编译，但编译照样报"成功"。**

`tools/build.py` 的源文件列表是**显式写死的**，新文件不登记就**静默跳过**，
而且退出码是 0、`text` 段大小正常——**看起来一切正常**。
我们第一次编完就是这个情况，符号表里根本没有 `Diff_`。
→ 已登记新文件并在脚本里加了注释警告。
**纪律：加完新文件，必须查符号表确认它真的进去了。**

**坑二：编译期常量被优化器折叠，导致"换了宏但没换代码"。**

C++ 版最初把车型写成 `enum` + `const` 常量，然后用 `if (kChassisKind == kDiff)` 分派。
在 `-Os` 下编译器把它折叠成了一次**有符号比较**：1 号车（值 0）恰好走对，
**2 号车那份固件却仍然在跑麦轮公式**——编译不报错、符号表里两个内核都在、
只有跑数值才看得出来。
→ 改成**宏数值直接比**（`#if CRTC_IS_DIFF()`），优化器没有推理空间。
**并且把模拟器也改成必须单独编一份差速版**（`build_cpp.py sim_b`），
因为"用 1 号车那份 sim.elf 去测 2 号车的代码"是测不出来的。

**一个需要说明的规则判断**：机械组最初的设想是
"1 号车半自动（快）、2 号车不自动（手动）"。这**把奖励系数吃反了**。
手册 P17/P18：能量单元（白块，1 分）全自动 ×2、半自动 ×1.5；
**能量核心（黄块，4 分）全自动 ×1.5、半自动 ×1.25**。
乘数**作用在 4 分上的收益是作用在 1 分上的 4 倍**。

| 场景 | 得分 |
|---|---|
| 1 号车半自动拿 6 个白块 + 2 号车手动拿 2 个黄块 | 6×1.5 + 2×4 = **17 分** |
| **对调（黄块也给半自动）** | 6 + 2×4×1.25 = **16 分** |

**结论：2 号车也应该走半自动。**成本只是把半自动模式也对 2 号车编进去（同一套代码），
收益是每个黄块多 1 分。已在给机械组的反馈里提出。

**当前状态**：
- ✅ `firmware/Core/Src/chassis_diff.c`（C 版）+ `cpp/src/chassis.cpp` 的差速内核（C++ 版）都已落地；
- ✅ 两套都编译通过、符号表互斥、模拟器 30+ 项断言全绿；
- ✅ 编译/烧录流程见 `docs/` 下对应的操作说明；
- ⚠ **前铲斜面尚未做出实物**：车长只剩 7mm，必须先定"斜面做进现有长度内 / 折叠铲 / 抬升铲"三者之一，
  再出图打件；
- ⚠ 橡胶轮要等中期之后才换（中期只出 1 号车）；
- 【待实测】麦轮实际外径、装麦轮后的板面离地高度、TT 马达出轴规格（这四项决定 `TURN_K` 和高度栈要不要改）。

---

## 八、平地收集策略的反思：重新清点"平地上到底有几个方块"

### 功能描述

讨论"1 号车只做平地收集"时，我们必须先回答一个问题：
**平地上到底有几个方块是真正敞开的？** 结论比预想的少得多，直接改变了我们对 1 号车价值的判断。

### 开发历程

**第一步：把 18 个白块按"1 号车（麦轮、不上台阶）能不能碰"逐个过一遍。**

| 位置 | 形态 | 1 号车能拿吗 | 原因 |
|---|---|---|---|
| a8 | 地面角落 | ✅ | 纯平地 |
| h1 | 地面角落 | ✅ | 纯平地 |
| c4 | 桥下地面（净高 130） | ✅ | 纯平地，但要钻桥 |
| f5 | 桥下地面（净高 130） | ✅ | 纯平地，但要钻桥 |
| e8'、d1' 附属高台矮墙 | 距地 20mm | ❌ | **槽缝只有 0.75mm**，任何铲/爪都插不进 |
| e8、d1 台阶几何中心 | 150mm 高 | ❌ | 要上台阶 |
| e3、d6 台阶内侧 | 台阶上 | ❌ | 要上台阶 |
| 地图中心轴 4 个 | 中央高地脚下 | ❌ | 要爬 300mm |

**能稳定拿到的是 4 个。18 个白块里的 4 个。**

> **这条结论纠正了一个直觉**：我们原以为"平地收集"意味着"平地上很大一片都是我的"，
> 实际上场地是**障碍赛式的** —— 绝大多数白块被人为放在台阶上、槽里、高台上。
> **只靠"站在地面上够"这一条路，1 号车的得分天花板是 6 分（4 块 × 1.5）。**
>
> ⚠ **但"6 分"这个数是错的，第九节已经把它推翻了。** 这里表里的 4 个是"**纯地面**"的方块；
> 1 号车**本身就是从 h5 高台出发的**，它走桥就能摸到中央系统的白块和焦点黄块。
> **真实上限约 27 分，见下一节。** 保留此表是为了留下"我们怎么一步步想错的"的过程。

**第二步：算"堵门"（把方块留在场上不让对方拿）到底值多少分。**

统计口径必须先纠正：**方块在 0.75mm 的槽里，我方本来就拿不到**，
所以堵门的收益**不是"我多拿几分"，而是"对手少拿几分"**：

| 对手的自动化程度 | 对手本该拿 | 我方相对收益 |
|---|---|---|
| 半自动 | 2 × 1.5 | **3 分** |
| 全自动 | 2 × 2 | **4 分** |

**同时把坐标算出来，发现一件更要紧的事**（区块 300mm）：

| 位置 | 坐标 | 距谁近 |
|---|---|---|
| a1（红方 2 号启动区） | x=150, y=150 | — |
| **d1'**（堵门点 1） | **x=1050, y=150** | **离 a1 只有 900mm** |
| h8（蓝方 2 号启动区） | x=2250, y=2250 | — |
| **e8'**（堵门点 2） | **x=1350, y=2250** | **离 h8 只有 900mm** |
| h5（我方 1 号启动区） | x=2250, y=1350 | 到 d1' 约 **2376mm**、到 e8' 约 **1782mm** |

> **这两个"堵门点"，正好在对手 2 号车的家门口。**
> **我方车要跑 1.8~2.4 米过去，对手只需要动 900mm。堵门的人比被堵的人路更远。**

**第三步：发现一条规则层面的硬伤。**

手册的**一局结束条件**里有一条：**"一方全部机器人 1 分钟内无任何运动与机构活动"**。
而"堵门"这个动作本质上就是让车停在原地不动 ——
**停满 60 秒 = 主动触发自己的判负条件。** 这是这套战术最致命的规则风险。

**结论与对策**：
- 堵门**降级为备选**（只在比分领先时的最后 2 分钟顺手用），**不作为主战术**；
  ★ 而且第九节重算后，**1 号车的正经任务有 27 分要做完，根本没有时间去堵门** —— 这条更坚定了降级；
- 单次堵门 **≤40 秒**，且期间让某个机构**间歇动作**（例如储仓门每 10 秒开合一次），
  这样不满足"无任何运动**与**机构活动"的判负前提；
- **不为了堵门绕远路**，只做收集路线上的"顺手挡"。

**第四步：由此推出 1 号车末端的定案 —— 用「铲」，不用「爪」。**

这一步我们其实**早就有实测数据**（见 `docs/02_机械结构与3D打印.md`）：

| 版本 | 现象 | 结果 |
|---|---|---|
| v1：铲前缘是 **6mm 厚垂直墙** | 方块被一直**推到墙角**，就是上不来 | 成功率 **0** |
| v2：前缘倒成 **30° 斜面**（倒角约 10mm） | 方块被铲上车 | 成功率 **约 70%** |
| 侧向导板张开 **60° 喇叭口** | 斜撞弹开的方块被导流回中间 | 修掉剩余失败的主要原因 |

角度纪律：**>45° 太陡方块上不来、唇部易断；<20° 唇部太长会翘曲。30° 是实测出来的最优解。**

> **所以 1 号车的收集方案是**：**贴地前铲（前缘 30° 倒角）+ 两侧 60° 固定喇叭口导板**。
> **不做车头外接斜面**（车长 283 vs 红线 290，**只剩 7mm**，外接必超标），
> **不做可开合侧板**（多一个舵机 = 多一个故障点 + 多一路 5V 负载；
> 而喇叭口的收益固定角度就能拿到 90%）。
> 喉口按对角线算：`THROAT = CUBE_DIAG + 4 = 42.4 + 4 = **46.4mm**`，**一次只过一个方块**。

**第五步：1 号车"3 个舵机"的用途分配（这是中期指标 5 的硬需求）。**

| 舵机 | 用途 | 一举两得 |
|---|---|---|
| 舵机 1 | 前铲抬升（铲进去后抬起，防掉） | 收集功能 |
| 舵机 2 | **储仓门开合** | ★ 同时服务"方块携带"指标 |
| 舵机 3 | 视觉云台 / 侧导板 | 收集功能 |

⚠ **注意**：此处原写"导板"用舵机，第九节已改口 —— **导板用固定 60° 喇叭口，不占舵机**，
省下的这一路留给**洞穴探杆**（洞穴黄块 2 个值 10 分，是 1 号车最重的一块收入）。

⚠ **3 个舵机同时动会拉塌 5V**：我们实测 **MG995 启动/堵转电流到 1.2A**，
一把 MG995 转动就能让 STM32 复位（见 `docs/04_电源硬件与焊接.md`）。
代码里已有"**同一时刻只动一个舵机**"的串行机制 ——
**这正好也是指标 5 要求"非初始状态下保持相对静止"的天然条件**：不动的舵机就是静止的。

---

## 九、重算两车的任务量：纠正"平地收集只是边角料"的误判

### 功能描述

第八节得出结论"平地上只有 4 个白块是敞开的"之后，机械组立刻提了一个反问：
**"那全部压力不都压到 2 号车身上了？风险太大了。"**

这个反问是对的，而且它暴露出**我们自己前一节的判断有误** ——
我们当时只数了"**纯地面**"的方块，**漏掉了 1 号车从 h5 高台出发、沿桥就能摸到的东西**。
这一节把两车的任务量重新算一遍，结论是：**1 号车不是边角料车，它的任务是全场最重的那一份。**

### 开发历程

**第一步：先承认误判在哪。**

第八节那张表只回答了一个问题："**不上台阶、站在地上，能拿到几个？**"答案是 4 个。
但 1 号车的**出发点本身就在 300mm 高台上**（h5），它可以**在台上跑**——
"平地收集"不等于"只能在地面收集"。所以那张表**低估了 1 号车**。

**第二步：把 1 号车"从 h5 出发、不下高台系统"能碰到的东西全部列出。**

| 目标 | 怎么够到 | 分值 |
|---|---|---|
| a8、h1、c4、f5 四个地面白块 | 从 h5 下到地面（有坡道 h3/h4），或自 a4 方向绕 | 4 × 1.5 = **6** |
| **中央高台面上的白块** | h5 → 桥 f5/g5 → e5，**全程走桥，不爬坡** | 4 × 1.5 = **6** |
| **中央焦点黄块**（1 个） | h5 → 桥 → 中央高地中心 | 4 × 1.25 = **5** |
| **d1、e8 洞穴里的黄块**（2 个） | 洞口在地面、开口向外，车头贴进去就能探 | 2 × 5 = **10** |
| **合计** | | **约 27 分** |

> **1 号车的上限从"6 分"跳到"27 分"。** 差的那 21 分，全是我们**没算"它能走桥"**这一条。

**第三步：2 号车（橡胶轮、爬坡走位）的实际任务。**

| 目标 | 怎么够到 | 分值 |
|---|---|---|
| e3、d6 物资架黄块（2 个，质心距地 250mm） | 上 150mm 台阶，用机械爪从架上取 | 2 × 5 = **10** |
| 高台面上的白块（台阶上、中央高地边缘） | 爬坡上高台 | 4 × 1.5 = **6** |
| **合计** | | **约 16 分** |

**第四步：三种分工的对比（这才是回答"风险"的正确方式）。**

| 方案 | 1 号车 | 2 号车 | 总分 | **单台最大占比** |
|---|---|---|---|---|
| A：全压一台车（机械组担心的那种） | 0 | 33 | 33 | **100%** ⚠ |
| B：我们上一轮的说法（1 号车只扫平地） | 6 | 24 | 30 | **80%** ⚠ |
| **C：按上表重新分工（本节结论）** | **27** | **16** | **43** | **63%** |

**结论：真正的风险不是"平地上方块少"，而是我们上一轮**自己**把 1 号车的任务砍到了 6 分。**
按本节重算之后：
- 两车任务量是 **27 : 16**，负担比从 80:20 降到 63:37 —— **单台车不再"输一台就崩盘"**；
- **总分从 30 涨到 43**（因为把"桥"和"洞穴"这两条路算进来了），**离理论上限 66 更近了**；
- **2 号车的任务反而变简单了**：它只需要"**爬上去 + 用爪取物资架**"这一件事，
  不用再指望它把白块也扫一遍。**它现在是专精车，不是主力车。**

**第五步：这个新分工对两车设计的影响（要同步给机械组的）。**

| | 1 号车 | 2 号车 |
|---|---|---|
| 末端 | 前铲（30° 斜面）+ 固定喇叭口导板 | 机械臂 + 夹爪（原方案不变） |
| **必须能下高台** | ★ 有（h3/h4 坡道下到地面，再自己回来） | 不需要 |
| 舵机需求 | 铲抬升 + 储仓门 + 导板 = **3 个**（满足指标 5） | 大臂 + 夹爪 + 腕 = 3 个（**官方只给每车 2 个 SG90，需另配**） |
| 任务重心 | **数量**（白块 + 洞穴黄块，重复动作多） | **精度**（物资架取块，位置高、容错小） |

> ⚠ **一个必须提醒机械组的点**：方案 C 让 1 号车**必须能从高台下来再上去**。
> 我们查了一下，h5 到地面有 h3+h4 坡道（26.57°），麦轮下坡没问题，
> **但上坡是麦轮的弱项**（我们 10-08 实测过 TT 马达爬不上去）。
> 所以 1 号车的实际路线要改成：**先在地面把 a8/h1/c4/f5 收完 → 回不到 h5 就别硬爬，
> 直接从 a4 方向经桥进入中央系统**（a4 也是高台、有 a5/a6 坡道）。
> **这一条需要现场跑一次确认哪条路上得去**，标记为【待实测】。

**当前状态**：
- ✅ 分工结论已修正：**两车 27 : 16，最大单台占比 63%**，不再是 80% 的单点依赖；
- ✅ 总分预期从 30 提到 43；
- ⚠ **1 号车的上下高台路线未实测**（是本文档最大的待验证项）；
- ⚠ 洞穴黄块的探取方式（是"铲推"还是"挑杆勾"）需实物确认；
- 【待实测】中央高台面上的白块**到底有几个**（目前按 4 个估，需现场数）。

---

## 十、机构同构化与轮系选型：为什么"两车用一样的高臂机构"可以、"两车都换麦轮"不行

### 功能描述

机械组提出一个更彻底的想法：**两台车用同一套末端机构**（一根能升降的立柱 + 一根可 180° 转的平行柱 + 平行夹爪），
并且**干脆两台车都换成麦轮**，这样零件通用、备件减半。
这一节回答两件事：**这个机构能不能塞进尺寸红线**，以及**两车同轮系是否可行**。

### 开发历程

**第一步：先算尺寸包络 —— 高度是最宽裕的，长度是最紧的。**

| 方向 | 规则红线 | 当前设计 | 余量 |
|---|---|---|---|
| 长 | 290 mm | 283 mm | **仅 7 mm** ⚠ |
| 宽 | 195 mm | 162 mm | 33 mm ✅ |
| **高** | **210 mm** | **148 mm** | **62 mm** ✅ |

当前肩高链路（`docs/06`、`mechanical/gen_parts.py`）：

```
板面 30 → 立柱 22 → 甲板 4 → 机械臂增高座 27.5 → 肩高 136 → 大臂平放最高 148
                                                              ↑ 距 210 红线还有 62mm
```

**结论一：高度方向还有 62mm 可叠。**
"立柱能升降"这个设想在**高度**上完全放得下 —— 它本质上就是把现在的固定增高座（27.5mm）换成可动行程，
可用行程上限 62mm，**够用**。

**结论二：但转轴位置必须卡死。**
"平行柱 180° 转动"如果是**绕车体轮廓内的立柱自转**，宽度余 33mm 能吃下，没问题；
**如果是立柱向外伸出后再转，车长 283 + 外伸量会立刻突破 290** —— 检录直接不合格。
→ **这一条必须让机械组在图纸上标出转轴到车头前缘的距离，且该距离不得增加整车长度。**

**第二步：算"两车都换麦轮"的可行性 —— 卡在爬坡上。**

核心问题是那条 26.57°（坡比 0.5）的坡道。上坡所需的最小附着系数：

```
tan(26.57°) = 0.5  →  需要 μ ≥ 0.50（严格说 sin θ = 0.447）
```

各类轮子的实际表现：

| 轮子 | 有效附着系数 | 能否上坡 |
|---|---|---|
| 60mm 橡胶轮 | ≈ 0.9 | ✅ **能** |
| **麦轮** | **≈ 0.42** ⚠ | ❌ **打滑** |

麦轮为什么只有 0.42：**它的接地体是一圈斜 45° 的塑料小辊子，不是整块橡胶**。
沿前进方向的牵引力被 45° 的辊子方向"分解"掉一部分：

```
有效牵引系数 ≈ μ × cos(45°) = 0.6 × 0.707 ≈ 0.42  <  上坡所需 0.447
```

**这个结果和我们的实车体验一致**（10-08 实测：官方 TT 马达 1:48 在坡上扭矩不足约 30%）。
**两道墙叠加**：
1. **麦轮抓不住地**（斜辊子把牵引力卸掉三成）；
2. **TT 1:48 马达没劲**（扭矩差 30%）。

**两道都是硬件层面的物理限制，不是调参、加功率能绕过的 —— 加功率只会让轮子转得更快地打滑。**

**结论三：两车同轮系不可行；两车同机构可行。**

| 项 | 判断 | 理由 |
|---|---|---|
| 两车**同末端机构**（立柱升降 + 平行柱 + 平行夹爪） | ✅ **可行，且推荐** | 尺寸放得下（高余 62）；机构统一利于备件互换，也便于报"底盘/机构（全部）" |
| 两车**同轮系**（都改麦轮） | ❌ **不可行** | 麦轮上不了 26.57° 坡，会直接丢掉 2 号车那 16 分 |
| 靠"升降立柱"去够所有平台 | ⚠️ **只对一半** | **升降解决"够得高"，不解决"上得去"** —— 高台上的方块，车得先能爬上高台 |

**关键区分（写给我们自己看）**：

| 目标 | 车的位置 | 靠什么 |
|---|---|---|
| 地面 4 白块 | 地面 | 前铲 |
| **物资架黄块（离地 250）** | **地面** | ★ **立柱升降**（这正是增高座在做的事） |
| 洞穴黄块 | 地面 | 探杆 |
| 中央焦点黄块 / 高台白块 | **300mm 高台上** | **必须先爬上去** → 只有橡胶轮做得到 |

**第三步：结论落回分工 —— 机构统一，轮系分开。**

| | 1 号车 | 2 号车 |
|---|---|---|
| 轮系 | 麦轮（全向，负责精确对位） | **橡胶轮（必须保留，是唯一能爬坡的）** |
| 末端机构 | **立柱升降 + 平行柱 + 平行夹爪** | **同款**（同构，备件互换） |
| 主战场 | 平地 + 走桥进中央系统 | 爬坡上高台 + 取物资架 |

**"机构同构、轮系异构"是这套方案的最终形态** ——
统一的部分省了备件和调试，分开的部分是场地逼出来的，**没有任何一种轮子能同时"全向精确"和"能爬陡坡"**。

**当前状态**：
- ✅ 尺寸包络核算完成：**高度余 62mm 足够容纳升降机构**；转轴位置需机械组在图纸上锁定；
- ✅ "两车都换麦轮"判定为**不可行**（附着系数 0.42 < 所需 0.447，且有实测佐证）；
- ⚠ **麦轮上坡能力从未实测** —— 上述 0.42 是**用估计摩擦系数 0.6 推算的**，不是量出来的。
  三种实测结果对应三种打法（见下），**这一条比任何推演都重要**；
- ⚠ 立柱升降机构的**实际行程**（能用多少 mm）需要装配后实测，目前只有理论余量 62mm。

| 若现场实测 | 对应结论 |
|---|---|
| 麦轮上不去（预计大概率） | 保持"机构同构 + 轮系异构"，即当前方案 |
| 麦轮意外能上 | 两车可统一为麦轮（机构与轮系全同，备件最省） |
| 橡胶轮也上不去 | **整个爬坡路线作废**，退回"平地收集 + 顺手堵门" |

---

## 十一、机械臂改定：圆柱坐标机械臂（回转 + 升降 + 夹爪）

> 时间：**2026-10-10**（同一天内的第三次改）。本篇记录的是**当前生效的构型**，
> 取代 `## 六` 的"平行四连杆"。详细的"想错了 → 错在哪 → 怎么改 → 复算证据"
> 见 `docs/批判与修正记录.md` 的「10-10 第三次大改」。

### 功能描述

一台圆柱坐标机械臂装在车上，负责**把车头前方的方块抓起来、转 180°、投进车尾的储仓**。
三个自由度**互相独立、完全解耦**：

| 自由度 | 机构 | 驱动 | 范围 |
|---|---|---|---|
| **θ 回转** | 整根立柱绕底座竖直轴转 | SG90（PA11 / TIM1_CH4） | 0° ~ 180° |
| **Z 升降** | 滑座沿立柱上下直线滑（曲柄滑块） | SG90（PA1 / TIM2_CH2） | 行程 30.5mm |
| **夹爪开合** | 末端齿轮版平行爪 | SG90（PA0 / TIM2_CH1） | 闭合 26 / 张开 45 |

**工作空间是一个圆柱面**（工业版圆柱坐标机器人还有径向伸缩，我们按简化版去掉了）。
这一构型的好处是**不需要逆运动学、不需要姿态补偿**，PS2 手柄直接给三个舵机角度。

### 设计过程里的三个关键判断

**第一步：为什么放弃摆动臂 —— 看末端怎么动，不看静止外观。**
参考视频里那根机构，静止时看着像"斜着的平行四连杆"，但逐帧看**末端是竖直上下走直线**，
而且**整根杆在水平面内转动** —— 这说明它的主体是"**立柱 + 柱上滑座**"，
臂只是从滑座伸出来的一小段偏心横臂。按摆动臂做，每次抓取都要算姿态、都要让肘部补偿水平，
代码量和调试量都翻几倍，且**球坐标逆解对开环舵机没有意义**（±5~10mm 的定位误差已经把解算精度吃掉了）。

**第二步：升降用"曲柄滑块"，行程被连杆长度锁死。**
升降不能直接用一个舵机摇臂推 —— 那会变成"越推越斜"。改用曲柄滑块：

```
z_s = CY_CRANK_Z + R·sinφ − sqrt(L² − (R·cosφ)²)
```

连杆孔距 `L` 恒定 ⇒ **滑座位置由曲柄角唯一决定**，且行程恰好 = 2R。
取 R = 15.25 ⇒ **行程 30.5mm**。
反过来推，**曲柄中心必须落在滑座行程正上方约 L 处**：

```
CY_CRANK_Z = 销中心中位 137.75 + CY_LINK_L 48 = 185.75
```

这条推论带来一个**反直觉的后果**：升降舵机**不能装在回转盘上**（那里 z≈140，离 185.75 差 45mm，
连杆根本够不到），**必须吊到柱顶去**。

**第三步：立柱不能装东西，所以要专门加一件顶帽。**
滑座是"整圈套在立柱外面"的（单边只留 0.6mm 打印间隙），它走过的 z 段是 **134.5 ~ 197** ——
也就是说**立柱在 z<197 的整个外表面，都是滑座的禁区**，任何卡箍、耳片、支架都塞不进去。
滑座行程 30.5 + 滑座自身 32，把立柱从头到尾占满了。
⇒ **柱顶是唯一还能装东西的平面** ⇒ 新增 `36_arm_lift_cap`（顶帽），升降舵机吊在它下面。

⚠ 顶帽**必须是"盖"不能做成"套"**：内孔做成 `Φ34.6`（对着立柱内腔 34），
环形面压在柱壁（40×3）的端面上，四个 Φ2.2 固定孔才落得到肉上。
如果按"套管"做成内孔 Φ40.6，四个孔会全部落在空腔上方，**一颗螺丝都吃不住**。
也不能加外裙边 —— 滑座内腔只有 41.2。

### 高度栈（爪尖绝不允许低于甲板面）

```
甲板面 88.5（已含 4mm 板厚）
→ 回转底座 40（座顶 128.5）
→ 回转盘 6（盘顶 134.5）
→ 立柱 62.65（柱顶 197.15）
→ 滑座高 32，滑座底 ∈ [134.5, 165.0]
→ 销中心 = 滑座底 − 12 ∈ [122.5, 153.0]，中位 137.75
→ 曲柄中心 185.75 → 顶帽厚 6（帽顶 203.15）
→ 全车最高点 = 曲柄外缘 185.75 + 18.85 = 204.6（红线 210，余 5.4）
→ 爪架底 = 滑座底 − 24 − 46；爪尖 = 滑座底 − 70 ∈ [64.5, 95.0]
```

**曲柄必须做成"单臂 + 圆头"**：曲柄中心在 185.75，而横臂最高到 165 ——
对称双臂的下半截会扫到横臂。单臂最远点只有 R + 3.6 = 18.85，正好把全车最高压到 204.6。
**连杆也必须离开横臂那一层**：横臂在 `y ∈ [11,19]`，连杆放 `y ∈ [20,26]`，用一根 M3×25 螺丝串起来。

### 与五类目标的对账（爪尖可达 64.5 ~ 95.0）

| 目标 | 相对车底板 | 结论 |
|---|---|---|
| 焦点黄块（全场最高，70~100） | 70 ~ 100 | ✅ 最高档夹住下半截 |
| 中央高台面白块（车走桥上去） | 72.5 ~ 102.5 | ✅ 最高档 |
| 台阶面白块 | 87.5 ~ 117.5 | ⚠ 只够夹到下半截 7.5mm，当备选 |
| 物资架黄块（质心离地 250） | 161.5 | ❌ **差 155mm** → 走挑杆 `16_rack_hook` |
| 地面白块 | 0 ~ 30 | ❌ → 前铲 |
| 洞穴黄块 | 洞底 0~50 | ❌（爪外宽 74 > 洞宽 70）→ 探杆 `17_cave_probe` |

★ **物资架那个"差 155mm"是死结，不是调参能救的**：现在全车最高 204.6、红线 210，
只剩 5.4mm。想多够 155mm 就得把立柱和曲柄再加高 155 —— 车高变成 360mm，检录直接出局。
所以**分工上就不把物资架算给机械臂**。

### 检录姿态与一条固件互锁

检录/运输/待机姿态 = **yaw = 90°（爪朝车侧）+ 升降推到最高档**：

- 最高档爪尖 95.0 > 甲板面 88.5，余 6.5mm；
- 整车 283 × **178** × 204.6，**三条红线（290 / 195 / 210）都在内**。

⚠ 若换成最低档，**爪尖只有 64.5，会直接插进甲板 24mm**。爪是一条 42mm 高的"刀片"，
在回转扫过车体上方时会犁甲板。所以固件里**必须加一条互锁**：

```
|yaw − 90°| < 30° 时，禁止升降低于「最高档 − 6mm」
```

加了之后，任何误操作只会"转不动"，不会把甲板犁出一道沟。

### 8 个臂件与装配要点

| 件号 | 名称 | 外廓 mm | 备注 |
|---|---|---|---|
| `30_arm_base` | 回转底座 | 64 × 44 × 40 | SG90 竖装，舵盘朝上；★ y 向刻意做窄到 44 给爪让路 |
| `31a_arm_turntable` | 回转盘 | 64 × 44 × 6 | 4×Φ2.2 对舵盘（孔距 16.5） |
| `31b_arm_mast` | 立柱 | 40 × 40 × 62.65 | 空心方管，走线用 |
| `32_arm_carriage` | 滑座 | 52 × 52 × 32 | 内腔比立柱大 0.6（单边） |
| `33_arm_boom` | 爪横臂 | 38 × 24 × 8 | ★ **沿 Y 拉伸**，CAD 里是躺平的，装配要绕 X 竖起来 |
| `34_arm_lift_crank` | 升降曲柄 | 18 × 28 × 8 | ★ 沿 Y 拉伸；单臂 + 圆头；半径 15.25 |
| `35_arm_lift_link` | 升降连杆 | 56 × 8 × 6 | ★ 沿 Y 拉伸；孔距 48 |
| `36_arm_lift_cap` | 顶帽 | 60 × 60 × 6 | ★ 必须是"盖"不是"套" |

装配顺序：底座上甲板（扎带穿十字槽）→ 回转舵机坐进底座内腔 → 回转盘压舵盘 →
立柱插回转盘并字槽 → 滑座套上立柱 → 装顶帽 → 升降舵机吊顶帽下（轴心 z=185.75）→
装曲柄（销孔朝上斜）→ 横臂（销孔局部 x=36）→ 连杆用 M3×25 串（注意 y 分层）→
横臂末端装爪。

### 独立验算结果（`tools/check_arm_clearance.py`，纯 math）

**19 项检查、0 失败、1 警告**。抓到三处毫米级余量，全部记录在案：

| 位置 | 余量 | 处置 |
|---|---|---|
| 投放态爪尖 95.0 vs 仓底 94.5 | **0.5 mm** | 全车最紧，进场前必须实测 |
| 取块态爪指 128.0 vs 甲板前缘 127 | **1.0 mm** | 建议 `CY_BOOM_L` 52→56，**暂未改** |
| 滑座顶 197.00 vs 顶帽底 197.15 | **0.15 mm** | 固件里升降不跑满行程两端（那是曲柄死点） |

⚠ 以上**全部是设计值推演，不是实测**。装配后必须按第十一节末尾的待实测清单逐条量。

### 当前状态

- ✅ 8 件几何在 `gen_parts.py` 5.7 节定稿，41 个零件出图、41 个 STEP 出包；
- ✅ 高度栈 / 目标对账 / 三处余量全部经独立脚本复算；
- ✅ 检录姿态三条红线（长 283 / 宽 178 / 高 204.6）全部满足；
- ⚠ **固件尚未跟上**：`config.h` 的角度表、`arm.c` 的 `Arm_SetLift`、方向键映射、
  `auto_task.c` 的 `MACRO_RACK`/`MACRO_CAVE` 都还是摆动臂时期的写法，**待改**；
- ⚠ **互锁尚未实现**（`|yaw−90°|<30°` 时禁止低档升降），**这是上电前的前置条件**；
- ⚠ 三处毫米级余量、爪指离甲板前缘 1.0mm 等**全部未实测**。

---

## 十二、开源项目说明

> 手册要求：使用了开源项目用于制作及代码编写的，应当在文档末尾完整说明。

我们单独写了一篇 `docs/开源项目说明.md`，逐条列清楚三件事：**哪些代码是我们自己写的**、**参考了哪些公开资料**、**电脑上装了哪些开源软件（各是什么许可）**。

一句话：**代码是自己写的，协议和引脚是查公开资料搞清楚的，用的工具都有各自的开放许可。**

---

## 更新约定

- 每次有实质进展就往上加，按发生的先后顺序补进对应板块，不重写历史。
- 标 **`【待实测】`** 的地方，做实之后必须填真实数字，不能留设计值冒充实测值。

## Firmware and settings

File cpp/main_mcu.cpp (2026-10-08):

/* ============================================================================
 * main_mcu.cpp —— C++ 版固件入口（运动 + 机械臂 + 视觉 三合一）
 *
 * 【这个文件是干嘛的】
 *   烧进 STM32 之后，接上串口（PA9/PA10，115200），用串口助手发字符
 *   就能分别验证底盘、机构、视觉三块，不用烧四个固件来回切。
 *
 * 【上电前必读的三条安全前提】
 *   1. 第一次上电务必把车**架空**（四个轮离地），否则参数没标定时车会乱跑。
 *   2. 电池电压 ≥7.0V；DRV8833 的 nSLEEP 必须接高，否则电机根本不动。
 *   3. 舵机听到"吱吱"声立刻断电 —— 那是超行程在硬撑，会烧舵机。
 *
 * 【串口命令表（发一个字符即可，不用回车）】
 *   运动： w 前进  s 后退  a 左移  d 右移  q 左转  e 右转  x 停  z 斜走45°
 *          r 自动演示（前进 1.5 秒然后停）
 *   机构： 1 收起  2 待命  3 地面取块  4 台阶取块  5 入仓  6 挑物资架  7 洞窟
 *          8 放铲
 *   微调： [ ] 夹爪 ∓5°    - = 大臂 ∓5°    , . 前铲 ∓5°      m 打印当前角度
 *   视觉： v 造一帧测试数据（不用接摄像头也能验证解析）   V 打印视觉状态
 *   其他： h 帮助    0 急停解除
 * ==========================================================================*/

#include "crtc.hpp"

extern "C" {
#include "main.h"
#include "board.h"
#include "bsp.h"
}

using namespace crtc;

/* ---- 全局对象。都是 POD，静态存储期零初始化，靠 init() 显式初始化 ------ */
static Chassis      g_chassis;
static Servo        g_servo[kServoCount];
static ArmSequencer g_arm;
static VisionLink   g_vis;

static float    g_vx = 0.0f, g_vy = 0.0f, g_wz = 0.0f;
static uint32_t g_tCtrl = 0, g_tServo = 0, g_tLog = 0, g_tBat = 0;
static uint32_t g_demoEnd = 0;          /* 非阻塞演示的结束时间 */
static uint16_t g_demoSpeed = 0;

/* --------------------------------------------------------------------------- */
static void startPwm(void)
{
    HAL_TIM_PWM_Start(&htim4, TIM_CHANNEL_1);
    HAL_TIM_PWM_Start(&htim4, TIM_CHANNEL_2);
    HAL_TIM_PWM_Start(&htim4, TIM_CHANNEL_3);
    HAL_TIM_PWM_Start(&htim4, TIM_CHANNEL_4);

    HAL_TIM_PWM_Start(&htim2, TIM_CHANNEL_1);
    HAL_TIM_PWM_Start(&htim2, TIM_CHANNEL_2);
    HAL_TIM_PWM_Start(&htim2, TIM_CHANNEL_3);
    HAL_TIM_PWM_Start(&htim2, TIM_CHANNEL_4);
}

static void printHelp(void)
{
    hal::print("\r\n==== CRTC2026 C++ firmware (motion / arm / vision) ====\r\n");
    hal::print("move : w s a d q e  x=stop  z=45deg  r=demo\r\n");
    hal::print("arm  : 1 stow 2 ready 3 pick-ground 4 pick-step 5 store 6 rack 7 cave 8 scoop\r\n");
    hal::print("trim : [ ] grip   - = arm   , . scoop   m print angles\r\n");
    hal::print("vis  : v fake frame   V status\r\n");
    hal::print("misc : h help   0 clear emergency\r\n\r\n");
}

static void printStatus(void)
{
    const float *w = g_chassis.wheels();
    hal::print("w[%+.2f %+.2f %+.2f %+.2f] d[%.2f %.2f %.2f %.2f] "
               "sv[%3.0f %3.0f %3.0f %3.0f] arm=%s vbat=%.2f\r\n",
               w[0], w[1], w[2], w[3],
               g_chassis.mixer().duty(0), g_chassis.mixer().duty(1),
               g_chassis.mixer().duty(2), g_chassis.mixer().duty(3),
               g_servo[0].current(), g_servo[1].current(),
               g_servo[2].current(), g_servo[3].current(),
               g_arm.busy() ? "busy" : "idle",
               hal::vbat());
}

static void printAngles(void)
{
    hal::print("grip=%.0f arm=%.0f scoop=%.0f extra=%.0f\r\n",
               g_servo[kGrip].current(), g_servo[kArm].current(),
               g_servo[kScoop].current(), g_servo[kExtra].current());
}

/* 造一帧视觉数据：cls=2(黄块), x=+40, y=-10, w=60, h=60, area=3600 */
static void fakeVisionFrame(void)
{
    uint8_t f[14];
    int16_t x = 40, y = -10;
    uint16_t w = 60, h = 60, area = 3600;

    f[0] = 0xAA; f[1] = 0x55; f[2] = 2;
    f[3] = (uint8_t)(x & 0xFF);        f[4]  = (uint8_t)((x >> 8) & 0xFF);
    f[5] = (uint8_t)(y & 0xFF);        f[6]  = (uint8_t)((y >> 8) & 0xFF);
    f[7] = (uint8_t)(w & 0xFF);        f[8]  = (uint8_t)((w >> 8) & 0xFF);
    f[9] = (uint8_t)(h & 0xFF);        f[10] = (uint8_t)((h >> 8) & 0xFF);
    f[11] = (uint8_t)(area & 0xFF);    f[12] = (uint8_t)((area >> 8) & 0xFF);

    uint8_t chk = 0;
    for (int i = 2; i < 13; i++) chk ^= f[i];
    f[13] = chk;

    uint32_t now = hal::millis();
    for (int i = 0; i < 14; i++) g_vis.feedByte(f[i], now);

    hal::print("frame fed: cls=%d x=%d y=%d area=%u valid=%d\r\n",
               g_vis.frame().cls, g_vis.frame().x, g_vis.frame().y,
               g_vis.frame().area, g_vis.valid(now, 300) ? 1 : 0);
}

static void handleCmd(char c)
{
    switch (c)
    {
    /* --- 底盘 --- */
    case 'w': g_vx =  1.0f; g_vy = 0; g_wz = 0; break;
    case 's': g_vx = -1.0f; g_vy = 0; g_wz = 0; break;
    case 'a': g_vx = 0; g_vy =  1.0f; g_wz = 0; break;
    case 'd': g_vx = 0; g_vy = -1.0f; g_wz = 0; break;
    case 'q': g_vx = 0; g_vy = 0; g_wz =  1.0f; break;
    case 'e': g_vx = 0; g_vy = 0; g_wz = -1.0f; break;
    case 'x': g_vx = g_vy = g_wz = 0.0f; g_demoEnd = 0; break;
    case 'z': g_vx = 0.707f; g_vy = 0.707f; g_wz = 0; break;
    case 'r': g_demoSpeed = 1; g_demoEnd = hal::millis() + 1500; break;

    /* --- 机构 --- */
    case '1': g_arm.start(POSE_STOW,        hal::millis()); break;
    case '2': g_arm.start(POSE_READY,       hal::millis()); break;
    case '3': g_arm.start(POSE_PICK_GROUND, hal::millis()); break;
    case '4': g_arm.start(POSE_PICK_STEP,   hal::millis()); break;
    case '5': g_arm.start(POSE_STORE,       hal::millis()); break;
    case '6': g_arm.start(POSE_RACK,        hal::millis()); break;
    case '7': g_arm.start(POSE_CAVE,        hal::millis()); break;
    case '8': g_arm.start(POSE_SCOOP,       hal::millis()); break;

    /* --- 舵机在线微调（调好之后把角度抄回 cpp/src/arm.cpp） --- */
    case '[': g_servo[kGrip].setTarget(g_servo[kGrip].target() - 5.0f); break;
    case ']': g_servo[kGrip].setTarget(g_servo[kGrip].target() + 5.0f); break;
    case '-': g_servo[kArm].setTarget(g_servo[kArm].target() - 5.0f); break;
    case '=': g_servo[kArm].setTarget(g_servo[kArm].target() + 5.0f); break;
    case ',': g_servo[kScoop].setTarget(g_servo[kScoop].target() - 5.0f); break;
    case '.': g_servo[kScoop].setTarget(g_servo[kScoop].target() + 5.0f); break;
    case 'm': printAngles(); break;

    /* --- 视觉 --- */
    case 'v': fakeVisionFrame(); break;
    case 'V':
        hal::print("vis cls=%d x=%d y=%d w=%u h=%u area=%u\r\n",
                   g_vis.frame().cls, g_vis.frame().x, g_vis.frame().y,
                   g_vis.frame().w, g_vis.frame().h, g_vis.frame().area);
        break;

    case 'h': printHelp(); break;
    case '0': g_chassis.stop(); break;
    default: break;
    }
}

/* --------------------------------------------------------------------------- */
int main(void)
{
    HAL_Init();
    SystemClock_Config();
    BSP_InitAll();
    startPwm();

    g_chassis.init(kDefaultParams);
    g_servo[kGrip].init(kDefaultParams,  kGrip,  30.0f);
    g_servo[kArm].init(kDefaultParams,   kArm,   25.0f);
    g_servo[kScoop].init(kDefaultParams, kScoop, 60.0f);
    g_servo[kExtra].init(kDefaultParams, kExtra, 0.0f);
    g_arm.init(g_servo, kDefaultParams);
    g_vis.init();

    g_arm.start(POSE_STOW, hal::millis());   /* 上电就收到检录姿态 */

    printHelp();

    for (;;)
    {
        uint32_t now = hal::millis();

        /* 串口命令 */
        int ch = hal::uartRead();
        if (ch >= 0) handleCmd((char)ch);

        /* 演示：非阻塞，到点自动停 */
        if (g_demoEnd != 0)
        {
            if ((int32_t)(now - g_demoEnd) >= 0)
            {
                g_demoEnd = 0;
                g_vx = g_vy = g_wz = 0.0f;
            }
            else
            {
                g_vx = 0.5f; g_vy = 0.0f; g_wz = 0.0f;
            }
        }

        /* 底盘控制 5ms */
        if ((uint32_t)(now - g_tCtrl) >= 5)
        {
            float dt = (float)(now - g_tCtrl) * 0.001f;
            g_tCtrl = now;
            g_chassis.setTarget(g_vx, g_vy, g_wz);
            g_chassis.update(dt, now);
        }

        /* 舵机插值 10ms */
        if ((uint32_t)(now - g_tServo) >= 10)
        {
            float dt = (float)(now - g_tServo) * 0.001f;
            g_tServo = now;
            for (int i = 0; i < kServoCount; i++) g_servo[i].update(dt);
            g_arm.update(now);
            g_vis.update(now);
        }

        /* 电压补偿 500ms */
        if ((uint32_t)(now - g_tBat) >= 500)
        {
            g_tBat = now;
            g_chassis.setVbat(hal::vbat());
        }

        /* 状态打印 400ms */
        if ((uint32_t)(now - g_tLog) >= 400)
        {
            g_tLog = now;
            printStatus();
        }
    }
}

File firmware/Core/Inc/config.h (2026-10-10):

#ifndef __CONFIG_H
#define __CONFIG_H

/* ============================================================================
 * config.h —— 全车唯一「调参入口」
 *
 * 【给新手的话】调试期间你 95% 的时间只会改这个文件。改完重新烧录即可，
 * 不用动任何 .c。每一个宏后面都写了「调大的后果 / 调小的后果 / 什么现象该改它」。
 *
 * 标定顺序（务必按这个顺序，否则会互相干扰）：
 *   第 0 步  ROBOT_ID / PS2 按键极性
 *   第 1 步  MOTOR_x_DIR 轮转向
 *   第 2 步  MOTOR_DEADZONE 死区
 *   第 3 步  SPEED_GAIN_* 速度标定
 *   第 4 步  CHASSIS_ACC_* 加速度斜坡（防滑）
 *   第 5 步  舵机角度 SERVO_*_*
 *   第 6 步  半自动宏时间参数 AUTO_*
 * ==========================================================================*/

/* ---------------------------------------------------------------------------
 * 0. 身份与模式
 * -------------------------------------------------------------------------*/
/* 1 = 1号机（高台机，从 a4/h5 高台出发，走桥抢中央焦点）
 * 2 = 2号机（地面机，从 a1/h8 出发，扫地面能量单元 + 挑物资架/洞窟） */
#define ROBOT_ID                 1

/* 三档模式（SELECT 键循环切换：手动 → 半自动 → 全自动 → 手动…）
 *   MODE_MANUAL 纯手动：摇杆直接开车，不触发任何自动动作
 *   MODE_SEMI   半自动：操作手按 ○/△/□/× 触发一键宏，决策权在人
 *   MODE_FULL   全自动：车自己巡游找块、自动触发宏，人不用管（需组委会认定）
 *
 * ⚠ 递进关系：全自动是**在半自动的宏之上**加一层自动调度（auto_full.c），
 *   并没有重写抓取动作。所以必须先把半自动调稳，再上全自动。 */
#define MODE_MANUAL              0
#define MODE_SEMI                1
#define MODE_FULL                2

/* 上电默认模式。推荐 MODE_SEMI：中期考核靠它拿分，最稳。
 * 想上场测全自动，把这里改成 MODE_FULL，或上电后按 SELECT 切过去。 */
#define DEFAULT_MODE             MODE_SEMI

/* ---------------------------------------------------------------------------
 * 1. 电机与防滑（最重要的一个板块）
 * -------------------------------------------------------------------------*/
/* 轮转向修正：某个轮转反了，把对应位改成 -1。这是最常见的“车原地打转”元凶 */
#define MOTOR_LF_DIR             1
#define MOTOR_RF_DIR            -1
#define MOTOR_LB_DIR             1
#define MOTOR_RB_DIR            -1

/* 电机安装方向修正：如果整车前进/横移方向反了，但四个轮都同向，改这里
 *   FORWARD_SIGN 前后（摇杆向上应该是前进）
 *   STRAFE_SIGN  左右横移
 *   YAW_SIGN     自转方向 */
#define FORWARD_SIGN             1
#define STRAFE_SIGN              1
#define YAW_SIGN                 1

/* ============================================================================
 * ★★ 车型选择（A 车 = 1 号 = 麦轮 / B 车 = 2 号 = 橡胶轮）★★
 *
 * 两台车走差异化配置，轮型不同 → 运动学不同：
 *   A 车（麦轮）   ：四轮辊子，能前后 + 横移 + 自转 → Chassis_*（mecanum.c）
 *   B 车（橡胶轮） ：无横向自由度，只能前后 + 自转 → Diff_*（chassis_diff.c）
 *
 * 改这一行，其余所有逻辑（斜坡/死区/归一化/急停）完全共用。
 * ⚠ 换车型必须重新 build + 烧录 —— **两台车是两份固件**。
 *
 * 【B 车特有：转弯系数跟着轮径走】
 *   chassis_diff.c 里 TURN_K = ROBOT_HALF_TRACK / WHEEL_RADIUS，
 *   所以**换非 60mm 的轮子必须同步改 WHEEL_RADIUS**，否则转向量算错。
 * ==========================================================================*/
#define CHASSIS_TYPE_MECANUM     0   /* A 车：麦轮，全向 */
#define CHASSIS_TYPE_DIFF        1   /* B 车：橡胶轮，差速 */

#ifndef CHASSIS_TYPE
  #define CHASSIS_TYPE           CHASSIS_TYPE_MECANUM
#endif

/* 死区补偿（0~1）：TT 马达 + DRV8833 在占空比低于这个值时不转。
 *   现象：推小油门车不动，推到一半突然蹿出去 —— 说明死区调小了，调大。
 *   现象：轻推摇杆车就猛地窜一下 —— 说明死区调大了，调小。
 *   出厂建议 0.18，实测地面（白色地胶）一般落在 0.12~0.26 */
#define MOTOR_DEADZONE           0.18f

/* 死区补偿生效后的最小输出（防止抖动） */
#define MOTOR_MIN_OUT            0.00f

/* 速度增益：把「归一化速度 0~1」映射到「占空比 0~1」
 *   现象：车太慢、爬不上坡 —— 调大
 *   现象：车一给油门就打滑/抬头 —— 调小
 *   注意：>1.0 会被限幅，没意义
 *
 * ⚠ 前进增益和横移增益必须相等，否则斜着走会系统性偏方向。
 *   这一点是 tools/sim/run_sim.py 在模拟器里跑出来的实测结论：
 *   FORWARD=0.85 / STRAFE=0.80 时，推 45° 斜走，实际是 43.26°，偏了 1.74°，
 *   等于走 2 米横移 6 厘米。把两者设成一样，偏差归零。
 *
 * 【真要补偿横移效率低，应该往大调，不是往小调】
 *   设 前进实测速度 vf、横移实测速度 vs（同样满舵、同样 2 米掐表），
 *   横移更慢（vs < vf）说明横移损耗大，要给它**更大**的增益才走得一样快：
 *       新横移增益 = 旧横移增益 × (vf / vs)
 *   例：vf=0.55 m/s，vs=0.48 m/s -> 0.85 × (0.55/0.48) = 0.97
 *   没做过实测之前，先保持两者相等（0.85），这是最不容易出问题的起点。 */
#define SPEED_GAIN_FORWARD       0.85f
#define SPEED_GAIN_STRAFE        0.85f   /* 先和 FORWARD 保持一致，实测后再按上式调 */
#define SPEED_GAIN_YAW           0.45f   /* 自转最容易打滑，给小一点 */

/* ⚠ 上面两条只对 A 车（麦轮）有意义。B 车没有横移，STRAFE 被忽略。
 *   B 车自转抓地更好，可以给大一点；下面是 B 车专用增益。 */
#define SPEED_GAIN_YAW_DIFF      0.60f

/* 加速度斜坡（防滑核心）：单位 = 归一化速度 / 秒
 *   现象：起步轮子原地空转、车抖 —— 调小 ACC_UP
 *   现象：起步肉、反应慢 —— 调大 ACC_UP
 *   现象：松摇杆车还滑行很远、冲过目标 —— 调大 ACC_DOWN
 *   打滑严重（坡道/地胶脏）时：ACC_UP 降到 1.5 */
#define CHASSIS_ACC_UP           3.0f
#define CHASSIS_ACC_DOWN         6.0f
#define CHASSIS_YAW_ACC_UP       6.0f
#define CHASSIS_YAW_ACC_DOWN     12.0f

/* 起步助力（kick）：为克服静摩擦，起步瞬间额外叠一点占空比，持续 KICK_MS 后线性衰减
 *   现象：车“咔”一下才动、起步一顿 —— 调大 KICK_DUTY
 *   现象：起步猛点头 —— 调小 */
#define MOTOR_KICK_DUTY          0.12f
#define MOTOR_KICK_MS            120

/* 高速时限制自转（防离心打滑）：|ω| 上限 = YAW_LIMIT_BASE - YAW_LIMIT_K * 线速度
 *   现象：边走边转时整车甩尾 —— 调大 YAW_LIMIT_K（限制更狠）
 *   现象：高速行进时想转却转不动 —— 调大 YAW_LIMIT_BASE */
#define YAW_LIMIT_BASE           0.90f
#define YAW_LIMIT_K              0.60f

/* 满油门时车体的实际速度（m/s）与自转速度（rad/s）。
 *   标定方法：地上贴胶带量 2m，全油门直行掐表；自转掐表转 3 圈。
 *   这两个数只影响「横移/自转混合时」的手感比例，不填准也能跑，
 *   但填准之后斜着走才不会莫名其妙画弧。 */
#define CHASSIS_V_MAX            0.60f
#define CHASSIS_W_MAX            4.00f

/* 松摇杆后的处理：0=自由滑行(coast) 1=刹车(brake)
 *   地胶上滑得很远，建议 1；若刹车导致车身点头/齿轮打齿，改 0 */
#define MOTOR_IDLE_BRAKE         1
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

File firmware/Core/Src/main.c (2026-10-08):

/* ============================================================================
 * main.c —— CRTC2026 完整固件入口
 *
 * 这个文件只做四件事，别的东西都在各自模块里：
 *   1. HAL_Init + 系统时钟        -> bsp.c
 *   2. 外设初始化                  -> bsp.c
 *   3. App_Init()                  -> app.c
 *   4. while(1) { App_Tick(); }    -> app.c
 *
 * 【两个上电小功能】
 *   · 按住板载按键 PB5 再上电 -> 舵机中位标定模式（四个舵机锁定 90°，装舵盘用）
 *   · 上电串口会打印 SYSCLK，若不是 72000000 说明晶振没起振
 * ==========================================================================*/

#include "main.h"
#include "bsp.h"
#include "board.h"
#include "config.h"
#include "app.h"
#include "servo.h"
#include <stdio.h>

/* ============================================================================
 * 串口接收回调 —— 视觉数据入口
 *   每收到 1 字节 -> 喂给 vision.c -> 立刻再开下一次接收（这句不能漏）
 *   USE_VISION=0 时那些字节被直接丢弃，不影响任何东西。
 * ==========================================================================*/
void HAL_UART_RxCpltCallback(UART_HandleTypeDef *huart)
{
    if (huart->Instance == USART1)
    {
        App_UartRxCallback(huart, (uint8_t)g_uart1_rx);
        HAL_UART_Receive_IT(&huart1, (uint8_t *)&g_uart1_rx, 1);
    }
}

/* ============================================================================
 * 舵机中位标定模式
 *   装舵盘时必须知道机械中位在哪。按住 PB5 上电，四个舵机停在 90°，
 *   这时装舵盘/摆杆最准。装好后断电重启即恢复正常。
 * ==========================================================================*/
static void servo_calib_mode(void)
{
    printf("\r\n[SERVO CALIB] all servos forced to 90 deg.\r\n");
    printf("[SERVO CALIB] install horns now, then power-cycle.\r\n");

    HAL_TIM_PWM_Start(&htim2, TIM_CHANNEL_1);
    HAL_TIM_PWM_Start(&htim2, TIM_CHANNEL_2);
    HAL_TIM_PWM_Start(&htim2, TIM_CHANNEL_3);
    HAL_TIM_PWM_Start(&htim2, TIM_CHANNEL_4);
    __HAL_TIM_SET_COMPARE(&htim2, TIM_CHANNEL_1, 1500);
    __HAL_TIM_SET_COMPARE(&htim2, TIM_CHANNEL_2, 1500);
    __HAL_TIM_SET_COMPARE(&htim2, TIM_CHANNEL_3, 1500);
    __HAL_TIM_SET_COMPARE(&htim2, TIM_CHANNEL_4, 1500);

    while (1)
    {
        HAL_GPIO_TogglePin(LED_PORT, LED_PIN);
        HAL_Delay(100);
    }
}

/* ========================================================================== */
int main(void)
{
    HAL_Init();
    SystemClock_Config();
    BSP_InitAll();

    printf("\r\n==== CRTC2026 firmware ====\r\n");
    printf("SYSCLK = %lu Hz\r\n", SystemCoreClock);
    if (SystemCoreClock != 72000000UL)
        printf("[WARN] HSE failed, running on HSI. Fix the crystal!\r\n");

    /* 等电源稳定：电池接上时 5V 降压有上升沿，立刻动舵机会掉压复位 */
    HAL_Delay(200);

    if (HAL_GPIO_ReadPin(KEY_PORT, KEY_PIN) == GPIO_PIN_RESET)
        servo_calib_mode();

    App_Init();

    while (1)
    {
        App_Tick();
    }
}

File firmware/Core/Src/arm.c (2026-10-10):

/* ============================================================================
 * arm.c —— 机构动作序列器（串行执行，一次只动一个舵机）
 *
 * 【为什么必须串行】MG995 启动/堵转能到 1.2A，5V 那一小片降压模块根本带不动
 *   两路同时动 —— 表现就是「一动舵机 STM32 就复位 / PS2 掉线」。
 *   本文件的写法天然保证**同一时刻只有一路舵机在动**（下一步一定要等上一步到位），
 *   这也是中期指标 5「任意非初始状态下保持相对静止」的天然条件。
 *
 * 【★★ 回转的顺序铁律（改任何序列都不能违反）】
 *   回转 SG90 的扭矩账只有约 1.2 kg·cm（臂 + 爪约 200g、质心半径约 60mm），
 *   而 MG995 那一段的减速比很大、反驱阻力很大。所以：
 *        ① 先把臂抬到「水平」（SERVO_ARM_STOW）
 *        ② 再回转（SERVO_YAW_*）
 *        ③ 转到位之后，才允许摆臂去取块
 *   **绝对不许带着大角度差硬转** —— 那是扫齿的标准姿势。
 *
 * 【五个舵机分别管什么】
 *   SERVO_ARM   MG995  整条平行四连杆臂上下摆（φ = −50°~+90°）
 *   SERVO_YAW   SG90   整条臂绕竖直轴转（0° 正前 / 180° 正后）
 *   SERVO_GRIP  SG90   末端平行爪开合
 *   SERVO_SCOOP SG90   前铲（★ 地面方块全靠它）
 *   SERVO_EXTRA SG90   挑杆 / 洞窟探杆
 * ==========================================================================*/

#include "arm.h"
#include "servo.h"
#include "config.h"
#include <stddef.h>      /* NULL */

typedef struct {
    ServoId_t servo;
    float     angle;
    uint16_t  wait_ms;    /* 这一步到位后再等多少毫秒 */
} Step_t;

/* ---------------- 各个姿态的动作脚本（改动作顺序/角度就改这里） -------------- */

/* 收起（检录位）：先把臂抬平 → 再转到正后方 → 别的机构归位
 * 这是唯一一个「顺序错了就会撞储仓」的序列，别动它的次序。 */
static const Step_t seq_stow[] = {
    {SERVO_GRIP,  SERVO_GRIP_OPEN,    120},   /* 先松爪，别攥着东西转 */
    {SERVO_ARM,   SERVO_ARM_STOW,     350},   /* ① 抬平 */
    {SERVO_YAW,   SERVO_YAW_STOW,     450},   /* ② 转到正后方（行程最长，给足时间） */
    {SERVO_SCOOP, SERVO_SCOOP_TRAVEL, 150},
    {SERVO_EXTRA, SERVO_EXTRA_IN,     120},
};

/* 待命：臂转回正前方并抬平，前铲放下准备收块 */
static const Step_t seq_ready[] = {
    {SERVO_ARM,   SERVO_ARM_STOW,     300},   /* ① 先抬平才能转 */
    {SERVO_YAW,   SERVO_YAW_FRONT,    450},   /* ② 转回正前方 */
    {SERVO_GRIP,  SERVO_GRIP_OPEN,    150},
    {SERVO_SCOOP, SERVO_SCOOP_DOWN,   200},
};

/* ★ 地面取块：**只用前铲，机械臂完全不参与**
 *   为什么不让臂来夹？因为 φ 要压到 −60° 以下爪子才够得着地面，
 *   而 −50° 以下主臂就扫到收集铲了 —— 这是几何死结（见
 *   tools/check_arm_clearance.py 的输出）。
 *   车前进由 auto_task.c 控（宏 AUTO_APPROACH_*），这里只管铲的姿态：
 *   放铲贴地 → 兜住（抬起一点把块压在铲里）→ 回行驶位。 */
static const Step_t seq_pick_ground[] = {
    {SERVO_SCOOP, SERVO_SCOOP_DOWN,   200},   /* 放铲贴地，等车推过来 */
    {SERVO_SCOOP, SERVO_SCOOP_UP,     AUTO_STORE_SETTLE_MS},   /* 兜住，块就跟着车走 */
};

/* ★ 台阶 / 高台面取块（用臂）：臂转到正前 → 摆到那个高度 → 夹 → 举高
 *   台阶面白块 150~180 → SERVO_ARM_STEP (φ=+19°)
 *   中央高台面白块（相对车底板 135~165）→ 把 SERVO_ARM_STEP 换成 PLATFORM (φ=+11°) */
static const Step_t seq_pick_step[] = {
    {SERVO_ARM,   SERVO_ARM_STOW,        300},   /* 先抬平 */
    {SERVO_YAW,   SERVO_YAW_FRONT,       450},   /* 转正前 */
    {SERVO_GRIP,  SERVO_GRIP_OPEN,       150},
    {SERVO_ARM,   SERVO_ARM_STEP,        AUTO_LIFT_SETTLE_MS},
    {SERVO_GRIP,  SERVO_GRIP_HOLD_CUBE,  AUTO_GRIP_SETTLE_MS},
    {SERVO_ARM,   SERVO_ARM_LIFT,        AUTO_LIFT_SETTLE_MS},
};

/* 中央焦点黄块（相对车底板 70~100）→ SERVO_ARM_FOCUS (φ=−26°) */
static const Step_t seq_pick_focus[] = {
    {SERVO_ARM,   SERVO_ARM_STOW,        300},
    {SERVO_YAW,   SERVO_YAW_FRONT,       450},
    {SERVO_GRIP,  SERVO_GRIP_OPEN,       150},
    {SERVO_ARM,   SERVO_ARM_FOCUS,       AUTO_LIFT_SETTLE_MS},
    {SERVO_GRIP,  SERVO_GRIP_HOLD_CORE,  AUTO_GRIP_SETTLE_MS},
    {SERVO_ARM,   SERVO_ARM_LIFT,        AUTO_LIFT_SETTLE_MS},
};

/* ★★ 入仓（把爪里的块放进储仓）—— 本方案的核心动作
 *   储仓最后一列正好在「臂朝正后方 + 水平」时爪子的正下方，
 *   落差只有 22mm，是全仓最温和的投料位。
 *   顺序：抬平 → 转正后 → 松爪 → 保持收起。 */
static const Step_t seq_store[] = {
    {SERVO_ARM,   SERVO_ARM_STOW,        350},   /* 先把块举平 */
    {SERVO_YAW,   SERVO_YAW_STOW,        450},   /* ② 转到正后方（块从车上空划过，安全） */
    {SERVO_ARM,   SERVO_ARM_STOW,        250},   /* 落位 */
    {SERVO_GRIP,  SERVO_GRIP_OPEN,       250},   /* 松爪，块掉进仓（落差 ≈22mm） */
    {SERVO_EXTRA, SERVO_EXTRA_IN,        100},
};

/* 挑物资架黄块：抬到最高（φ=+90，只能夹住黄块下半截）
 * ⚠ 队长指示：现场要是拿不下来就**直接放弃**，别为它超时。
 *   车体前进/后退由 auto_task.c 控（AUTO_RACK_*）。 */
static const Step_t seq_rack[] = {
    {SERVO_ARM,   SERVO_ARM_STOW,        300},
    {SERVO_YAW,   SERVO_YAW_FRONT,       450},
    {SERVO_GRIP,  SERVO_GRIP_OPEN,       150},
    {SERVO_ARM,   SERVO_ARM_RACK,        AUTO_RACK_LIFT_MS},
    {SERVO_GRIP,  SERVO_GRIP_HOLD_CORE,  AUTO_GRIP_SETTLE_MS},
    {SERVO_ARM,   SERVO_ARM_LIFT,        AUTO_LIFT_SETTLE_MS},
    {SERVO_EXTRA, SERVO_EXTRA_OUT,       200},   /* 挑杆帮一下：把黄块沿 φ14 圆柱往外拨 */
};

/* 洞窟探杆（爪进不去 70mm 的洞，只能靠它） */
static const Step_t seq_cave[] = {
    {SERVO_ARM,   SERVO_ARM_STOW,        300},   /* ★ 收臂让开，别跟探杆抢空间 */
    {SERVO_YAW,   SERVO_YAW_STOW,        400},
    {SERVO_EXTRA, SERVO_EXTRA_OUT,       250},
    {SERVO_EXTRA, SERVO_EXTRA_IN,        250},
};

static const Step_t seq_scoop_toggle[] = {
    {SERVO_SCOOP, SERVO_SCOOP_DOWN,     200},
};

typedef struct {
    const Step_t *seq;
    uint8_t       len;
} Seq_t;

static const Seq_t g_seqs[] = {
    {NULL,              0},
    {seq_stow,          sizeof(seq_stow)/sizeof(Step_t)},
    {seq_ready,         sizeof(seq_ready)/sizeof(Step_t)},
    {seq_pick_ground,   sizeof(seq_pick_ground)/sizeof(Step_t)},
    {seq_pick_step,     sizeof(seq_pick_step)/sizeof(Step_t)},
    {seq_store,         sizeof(seq_store)/sizeof(Step_t)},
    {seq_rack,          sizeof(seq_rack)/sizeof(Step_t)},
    {seq_cave,          sizeof(seq_cave)/sizeof(Step_t)},
    {seq_scoop_toggle,  sizeof(seq_scoop_toggle)/sizeof(Step_t)},
    {seq_pick_focus,    sizeof(seq_pick_focus)/sizeof(Step_t)},
};

static uint8_t    g_busy = 0;
static uint8_t    g_idx  = 0;
static uint32_t   g_t_mark = 0;
static ArmPose_t  g_cur_pose = POSE_NONE;
static uint8_t    g_scoop_down = 0;

void Arm_Init(void)
{
    g_busy = 0; g_idx = 0; g_cur_pose = POSE_NONE; g_scoop_down = 0;
    Arm_Start(POSE_STOW);
}

void Arm_Start(ArmPose_t pose)
{
    if ((int)pose <= 0 || (int)pose >= (int)(sizeof(g_seqs)/sizeof(Seq_t))) return;
    g_cur_pose = pose;
    g_idx      = 0;
    g_busy     = 1;
    g_t_mark   = HAL_GetTick();
    /* 立刻下达第一步 */
    Servo_SetAngle(g_seqs[g_cur_pose].seq[0].servo,
                   g_seqs[g_cur_pose].seq[0].angle);
}

/* 每 1~5ms 调用一次即可，内部自己计时 */
void Arm_Update(uint32_t now_ms)
{
    if (!g_busy) return;

    const Seq_t *s = &g_seqs[g_cur_pose];
    if (g_idx >= s->len) { g_busy = 0; g_cur_pose = POSE_NONE; return; }

    const Step_t *st = &s->seq[g_idx];

    /* 当前舵机还在动 -> 等 */
    if (Servo_IsMoving(st->servo)) { g_t_mark = now_ms; return; }

    /* 到位了，还要等 wait_ms */
    if ((uint32_t)(now_ms - g_t_mark) < st->wait_ms) return;

    /* 下一步 */
    g_idx++;
    if (g_idx >= s->len)
    {
        g_busy = 0;
        g_cur_pose = POSE_NONE;
        return;
    }
    Servo_SetAngle(s->seq[g_idx].servo, s->seq[g_idx].angle);
    g_t_mark = now_ms;
}

uint8_t   Arm_IsBusy(void)  { return g_busy; }
ArmPose_t Arm_Current(void) { return g_cur_pose; }

void Arm_Grip(float angle)
{
    Servo_SetAngle(SERVO_GRIP, angle);
}

void Arm_ScoopDown(uint8_t down)
{
    g_scoop_down = down;
    Servo_SetAngle(SERVO_SCOOP, down ? SERVO_SCOOP_DOWN : SERVO_SCOOP_TRAVEL);
}
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

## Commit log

2026-10-08 工程仓库初始化：固件 + 3D 打印交付 + 工程日志 + 工具链
    固件（STM32F103C8T6 / HAL）：底盘麦轮运动与防滑、PS2 手柄 SPI、舵机机构序列、半自动宏、视觉接口；均为自写 hal_shim 纯寄存器实现。
    3D 打印交付：25 结构件 + 14 外观件 STL、图纸集、切片与打印手册、打印清单。
    docs/：工程日志 00~09、调参指南、硬件接线与焊接指南、半自动/全自动操作手册。
    C++ 离线验证版：chassis/motor/servo/arm/vision + 模拟器断言。
    工具链：build.py / flash.py / slice_k1.py / gen_parts.py / 仿真脚本。
    新增 .gitignore：排除 firmware/build、cpp/build 等编译产物与 .wor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
    [01_deck_front.dxf, 01_deck_front.stl, 02_deck_rear.dxf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]
2026-10-08 整理工程日志与文档结构，对齐手册 4.3.1 文档规范
    新增 docs/工程日志.md：主日志，以「具体功能（H2 标题）+ 功能描述与开发历程」组织 11 个功能板块，按推进顺序排列，并如实区分「已实测跑通」与「待实车验证」。
    新增 docs/开源项目说明.md：按手册要求完整说明所用开源项目、参考的公开资料与各自许可。
    重写 docs/00 总览：原稿的时间线把计划写成了已发生，改为真实进度快照（已完成 / 代码完成待验证 / 仅设计三档）。
    重写 README：加入文档规范逐条对照表、目录结构与真实交付状态。
    把根目录 3 份 md 移入 docs/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
2026-10-08 补充实车爬坡问题的分析与对策
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2026-10-08 Document robot slope performance issues and solutions
    Added detailed analysis and recommendations for improving robot performance on steep slopes, including motor specifications, weight considerations, and potential upgrades.
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2026-10-08 总览与战术选型同步两车差异化：修正弃爬坡旧结论并补充物资分配
2026-10-09 两车物块获取方案：差速转向内核（C/C++ 双实现）+ 场地几何认证
    ## 一、新增 B 车（2 号车，橡胶轮）差速转向
    橡胶轮没有辊子，横移自由度在物理上不存在，照抄麦轮逆解会让四轮两两
    反向对打（车原地抽搐、电流翻倍、且不报错）。新增独立的差速内核：
    w_左 = vx + K·wz K = 半轮距 / 轮半径 = 2.2667
    w_右 = vx - K·wz
    * firmware/Core/Src/chassis_diff.c + chassis_diff.h （C，比赛固件）
    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
2026-10-09 重算两车任务量：1号车走桥可达中央系统，分工由 80:20 改为 63:37（总分 30→43）
    - 工程日志新增第九板块，原第九节开源说明顺延为第十节
    - 第八板块加推翻标注（平地方块只有4个/6分 作废，保留过程）
    - 舵机分配改口：侧导板改固定喇叭口不占舵机，让位给洞穴探杆
    - 总览文档两车分工表更新为 27 / 16
2026-10-09 工程日志新增第十板块：机构同构化与轮系选型
    - 尺寸包络核算：高余62mm 可容纳升降机构；长仅余7mm，转轴须在轮廓内
    - 判定两车都换麦轮不可行：麦轮有效附着 0.42 < 上坡所需 0.447
    - 结论：机构同构、轮系异构；升降只解决够得高，不解决上得去
    - 原第十节开源说明顺延为第十一节
2026-10-09 工程日志补充工具链路线说明：CubeIDE 单件与学院推荐五件套的功能对照
    - 说明 CubeCLT/CubeProgrammer/驱动 三项功能 CubeIDE 已自带，不是少装
    - 记录两条有意取舍：不用 CubeMX 生成代码、不装 CubeMonitor
    - 说明 VSCode 替代 CLion 的理由
2026-10-10 机械臂整体换为平行四连杆方案；固件扩到 5 路舵机（TIM1_CH4/PA11）
    机械臂（照参考视频重做，推翻 10-08 的两自由度平面连杆臂）
    - 新增件 30_arm_base / 31a_arm_turntable / 31b_arm_mast / 32_arm_link x2 / 33_arm_elbow
    - 平行四连杆：主臂与平行杆等长 105 且始终平行 -> 肘座姿态恒定水平 -> 爪指永远朝下
    - 三舵机：MG995 摆臂(phi -50~+90) + SG90 回转(yaw) + SG90 齿轮版平行爪，满足指标 5
    - 高度栈第 4 次重算：AB_SERVO_DZ 10->18，最高点 196.5 < 210（余 13.5）
    - 收起姿态 = yaw 180 朝正后方 + phi 0 水平平躺，车长仍 283（余 7）
    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
    [01_deck_front.stl, 02_deck_rear.dxf, 02_deck_rear.stl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]
2026-10-10 机械臂改定为圆柱坐标：几何/验算/交付包全线同步
    构型（10-10 第三次大改，推翻平行四连杆）：
    - 柱坐标臂 = θ回转 + Z升降(曲柄滑块) + 夹爪开合，三自由度解耦、不用逆解
    - 曲柄滑块闭合条件 → CY_CRANK_Z = 销中位137.75 + 连杆48 = 185.75
    ⇒ 升降舵机必须吊在柱顶，不能装在回转盘上
    - 立柱 z<197 全被滑座包住 ⇒ 新增 36_arm_lift_cap 顶帽（必须是盖不是套，内孔Φ34.6）
    - 爪偏心 52（60车长超限/38扫到自有底座），配套底座改 64x44 窄矩形
    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
    [01_deck_front.stl, 02_deck_rear.stl, 03_deck_splice.stl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]
2026-10-13 烧录通道改为 OpenOCD 优先：解决克隆版 ST-LINK 与 CubeProgrammer 不兼容
    ★ 根因（2026-10-13 实测，不是线的问题）：
    - 我们的 ST-LINK 是克隆版 V2、固件 V2J29S7；CubeProgrammer v2.23 与它握不上手：
    一律 ST-LINK error (DEV_CONNECT_ERR)，-l 里 'ST-LINK FW :' 读出空白，
    命令到报错只用 32ms（根本没走到跟目标握手）。
    已排除：环境(编译正常)、进程占用(杀掉 stlinkserver 仍失败)、
    参数(六组 freq/mode 全失败)。
    - 同一块板、同一把线，OpenOCD 一次连上：
    STLINK V2J29S7 / Target voltage 3.18V / SWD DPIDR 0x1ba01477 /
    Cortex-M3 r1p1 detected / Examination succeed
    - ⇒ DEV_CON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
2026-10-13 motion 固件加板载 LED 心跳：没串口也能确认固件在跑
    问题：test_motion.c 全文一行 LED 代码都没有 —— 烧完固件后板子毫无动静
    （LED 不闪 + 没插串口），用户完全无法确认固件是否在运行。
    改动 firmware/Core/Src/test_motion.c：
    - 启动指示：主循环前快闪 3 下（= 初始化完成）
    - 待机心跳：主循环每 500ms 翻转 PC13（1Hz 慢闪）
    - 指令应答：HAL_UART_RxCpltCallback 里 g_led_flash=20，收到字节后快闪约 1.2s
    - 文件头注释新增「板载 LED 心跳」整段（含 LED 不亮 / 疯狂快闪两种异常的含义）
    - 引脚沿用 board.h 的 LED_PORT=GPIOC / LED_PIN=GPIO_PIN_13（低电平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
2026-10-19 新增电气组工作日志（王紫怡）
    王紫怡（电气组）10/05-10/19 的焊接与电源布线记录，由陶家宇整理入库。
    按手册"文档规范"重构结构：原文按日期流水记录，改为 8 个功能 H2 板块
    （约束清点 / 三路电源隔离 / 焊接工艺 / 排母装配 / 信号桥 / 电源站与马达线 /
    洞洞板改面包板 / 全链路验证），日期降为板块内时间锚点，内容一字未删。
    末尾补"开源项目与外部参考说明"一节，满足手册对开源四要素的要求。
2026-10-19 中期材料整理：补实物照片、实际采购金额、按素材标定指标状态
    一、docs/images/ 新增 16 张实物照片（2.96MB）
    整车 3 张、尺寸测量 4 张、前铲打印件 4 张、
    电气接线 5 张（洞洞板/走线/PS2 接收器/STM32/ST-LINK）。
    仓库此前没有任何图片引用，这是第一批。
    二、docs/工程日志.md
    - 第一节插整车三视图，第二节插 PS2 接收器，第十二节插前铲四张实物
    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
2026-10-19 文档按最终方案校正：机械臂未采用，改为前铲 + 储仓
    10-19 定稿的方案与文档里记载的已经不一致，本次只改"方案陈述"，不改历史记录。
    工程日志：
    - 十一节开头加变更说明：柱坐标机械臂 8 件已出图但未打印、未装配，最终没采用。
    原因写明是工作空间与目标分布对不上（爪尖最低 64.5 vs 地面块顶 30，差 34.5；
    物资架黄块 250 vs 爪尖最高 95，差 155），不是画错。
    - 七节两车分工表：2 号车从"机械爪抓取"改为"转臂扫落 + 1 号车地面收"，
    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
2026-10-19 如实交代底盘运动学的公式来源；机械臂三版设计全部留档
    队长指出的两件事，改的是事实陈述，不涉及任何代码。
    一、麦轮逆解不是我们自己推的
    原文档写"手推了逆解公式""推导过程见代码注释"，开源说明里写"麦轮解算
    全部自己写""代码是我们自己写的"——这与实际不符。麦轮逆运动学是公开的
    经典公式，全向底盘的开源实现和入门教程给出的都是同一组式子。
    - docs/工程日志.md 第一节：改"手推逆解公式"为"对着公开资料把公式看懂、
    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
2026-10-19 接入实车烧录版固件 firmware_v2（中期考核这一版车跑的就是它）
    firmware_v2/ 是外部给的裸机工程（无 HAL / 无 CubeMX），我们烧进车上那颗
    STM32F103C8T6 的最终版本。仓库里原来只有自研的 firmware/（含舵机 / 机械臂 /
    半自动宏），读者容易搞混哪一套是实车在跑的，这次把实车版纳入版本控制，
    并在 README 里写清两者的分工。
    相对原始包的 6 处改动（4 个文件，13 个文件里 9 个字节未动）：
    1. board_config.h BOARD_WATCHDOG_ENABLE 1→0
    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
2026-10-19 同步当日的自研主固件改动：机械臂改定后的舵机/机械臂/PS2 与新增测试固件
    这批改动是 10 月中下旬在自研主固件 firmware/ 上做的，之前一直只在本地工作区，
    仓库里还是旧代码。按文件归类：
    机械臂与舵机
    - arm.c / arm.h（+308 / +73）：机械臂由平行四连杆改为柱坐标构型后重写，
    三轴（回转 / 升降 / 夹爪）行程表、姿态表、互锁时序。
    - servo.c / servo.h：舵机输出改为 50Hz + 比较寄存器直填微秒值，加缓动限速。
    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
2026-10-21 车二支持：新增挑杆舵机通道（TIM2_CH3 / PA2），用编译开关与车一隔开
    车二与车一同一套底盘和遥控，只多一个上下摆动的挑杆。驱动它只需要一路舵机信号，
    所以做成编译开关而不是分裂成两套代码 —— 车一那版行为不变。
    新增
    - src/servo_lift.h / .c：TIM2_CH3（PA2）输出 50Hz 标准舵机信号。
    PSC=63 → 1MHz 计数，ARR=19999 → 20ms；脉宽 600~2400us，上电中位 1500us。
    按住 R1 抬、按住 R2 降，速度 900us/s（全程约 2 秒），松开保持。
    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
2026-10-21 车二挑杆舵机改回材料里定的 PA3（TIM2_CH4），此前误用 PA2
    核对时发现的问题：`docs/硬件接线与焊接指南.md` 第 87~90 行已经把四路舵机定死了，
    `firmware/Core/Inc/board.h` 也是同一套：
    PA0 TIM2_CH1 夹爪
    PA1 TIM2_CH2 臂升降
    PA2 TIM2_CH3 前铲（车一在用）
    PA3 TIM2_CH4 备用 / 挑杆 ← 车二的挑杆本来就该走这一路
    上一个提交把挑杆放在了 PA2（前铲那一路）。电气上能用（车二没有前铲），
    但与我们自己冻结的引脚表对不上，属于不必要的人为偏差，改回来。
    改动
    - board_config.h：BOARD_SERVO_PORT_PIN 2 -> 3。
    - servo_lift.c：通道 CH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
2026-10-26 补齐车一的舵机与整车演示，README 与文档去掉宣传腔
    固件：
    - board_config.h 补上 5 个 BOARD_SERVO_* 宏（此前全工程没有定义，
    带舵机的编译开关一直编不过）；stm32f103_min.h 补 TIM2 基址
    - main.c 接上 servo_lift 的初始化与每周期步进（R1/R2 控制）
    - 新增 selftest_main.c：四轮分别慢速转，每轮 4 秒、间隔 1.5 秒
    - 新增 demo_main.c：整车演示，15 段共 24 秒，覆盖麦轮五种动作与
    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
2026-10-26 加入三段实车调试录像
    视频放在 docs/videos/，手机原片是 HEVC 编码，部分播放器不认，
    统一转成 H.264 + faststart，浏览器和手机都能直接打开。
    文件名按内容改成可读的，原来的哈希名不用了。
    三段都保留现场原声，没有剪——对话里能听出当时在试什么。
    docs/videos/README.md 记了每段多长、拍的什么状态。
    封面帧抽在 docs/images/video-0X-cover.jpg。
    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
2026-10-27 diag: 把 PS2 服务状态接进诊断工具，纠正两处会误判的结论
    实测记录（车一，板上只靠 ST-LINK 3.28V 供电）：
    - 固件在跑，last_loop_ms 正常递增，invalid_frames 每 10ms +1
    - g_ps2.stage = 0 —— 配置事务四步都走完并归零了，不存在"卡在配置模式"
    - g_ps2.fail_count 持续增长，last_length = 9，9 个字节全是 FF
    - valid_frames = 0
    结论：代码侧的锁定路径确实堵住了，问题在硬件侧（接收器一次都没拉低过 DAT）。
    工具改动：
    - main.c：把 Ps2Service 提成全局 g_ps2，OpenOCD 可以直接读
    stage / fail_count，比看帧数更快定位"是不是卡在事务里"
    - verify_v2.py：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
2026-10-27 诊断工具：修读存降速与扫描恢复目标
    - ps2_probe.read_block 加 adapter speed 500。这块克隆版 ST-LINK
    在 4MHz 下写 debug 寄存器会报 Failed to write memory at 0xe00fffec，
    降速后稳定。
    - ps2_scan.py 的 --restore 支持指定目标（原来写死 full），
    现在可以 --restore v2s 直接烧回车一固件。
    - 扫描"全不通"时的结论文案改准：不再直接归因于接收器坏，
    而是按 供电 → 5V/3.3V → 对频 → 虚焊 的顺序给排查项。
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2026-10-29 新增接手交接手册：全车接线 + PS2不传信号/ST-Link无法脱机 两个问题的排查步骤
